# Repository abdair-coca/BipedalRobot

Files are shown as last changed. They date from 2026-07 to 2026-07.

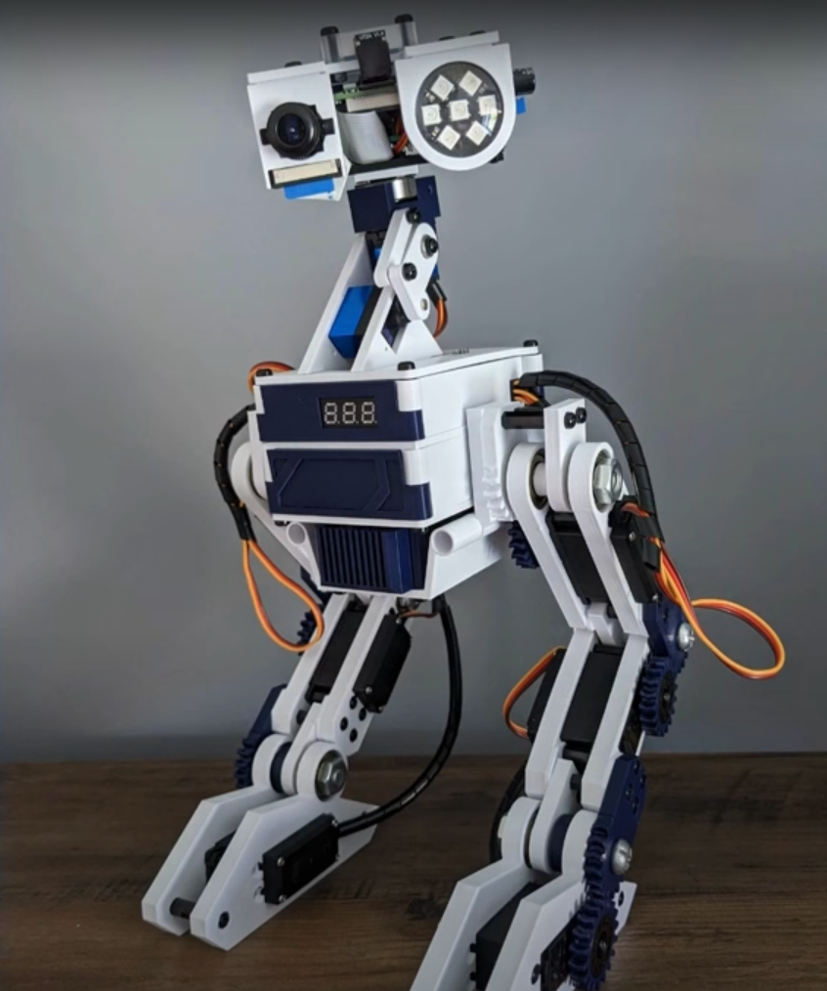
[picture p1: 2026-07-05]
docs/3dImages/propuesta.png

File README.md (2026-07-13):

# Bipedal Robot

Robot bipedo mediano (40-80cm) — proyecto portfolio/demo tecnico dentro del workspace **robotCreeper**.
Reutiliza y extiende el hardware/software ya desarrollado en robotCreeper (cabeza con camara, voz y cara OLED) montandolo sobre un cuerpo bipedo nuevo con piernas motorizadas y control de balance.

## Estructura del proyecto

| Carpeta | Contenido |
|---|---|
| [`docs/`](docs/) | Vision, alcance, arquitectura de sistema, roadmap, decisiones y riesgos |
| [`mecanica/`](mecanica/) | Diseno estructural, DOF de piernas, materiales |
| [`electronica/`](electronica/) | BOM, presupuesto energetico, conexionado |
| [`firmware/`](firmware/) | Arquitectura de firmware (ESP32 principal + nodos) |
| [`software/`](software/) | Control de marcha, cinematica, simulacion (a definir) |
| [`gestion/`](gestion/) | Backlog y milestones del proyecto |
| [`tests/`](tests/) | Tests de componentes especificos, aislados del firmware final |
| [`quadruped_rl_sim/`](quadruped_rl_sim/) | Experimento aislado: sim PyBullet+RL (PPO) de marcha en un cuadrupedo 12 DOF, previo a portar el enfoque al bipedo real |

## Punto de partida

- Empieza por [`docs/01-vision-alcance.md`](docs/01-vision-alcance.md)
- Arquitectura general en [`docs/02-arquitectura-sistema.md`](docs/02-arquitectura-sistema.md)
- Roadmap de fases en [`docs/03-roadmap-fases.md`](docs/03-roadmap-fases.md)

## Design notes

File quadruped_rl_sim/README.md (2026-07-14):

# quadruped_rl_sim

Simulacion PyBullet + Gymnasium + PPO (stable-baselines3) para entrenar la
marcha hacia adelante de un cuadrupedo generico de 12 DOF (3 por pata:
abduccion de cadera, pitch de cadera, rodilla).

**Este es un experimento aislado**, independiente del robot bipedo real del
resto del repo (`mecanica/`, `electronica/`, `firmware/`, etc.). Sirve como
banco de pruebas de RL con servos de posicion antes de portar el enfoque al
hardware bipedo. No comparte codigo ni archivos con esas carpetas.

## Por que cuadrupedo y no bipedo, para este experimento

Un cuadrupedo de 12 DOF es mas facil de estabilizar que un bipedo (mas puntos
de apoyo, menos sensible al balance), asi que sirve para validar primero la
mecanica de RL + control por posicion (URDF, entorno Gymnasium, PPO,
pipeline sim-to-real) con un problema mas simple, antes de pelear ademas con
el balance dificil de un bipedo.

## Instalacion

Requiere Python 3.11 (probado en Windows).

```bash
cd quadruped_rl_sim
python -m venv .venv
.venv\Scripts\activate         # cmd.exe
.venv\Scripts\Activate.ps1     # PowerShell
pip install -r requirements.txt
```

**Nota Windows importante**: `pybullet` no publica wheels precompilados para Windows
en PyPI (ninguna version) — `pip install` lo compila desde source, lo que requiere
**Microsoft C++ Build Tools** (workload "Desktop development with C++"). Si no los
tenes instalados, `pip install` va a fallar con `error: Microsoft Visual C++ 14.0 or
greater is required`. Instalar con:
```powershell
winget install --id Microsoft.VisualStudio.2022.BuildTools -e --override "--wait --quiet --add Microsoft.VisualStudio.Workload.VCTools --includeRecommended"
```
Alternativa sin compilar: instalar Miniconda y `conda install -c conda-forge pybullet`
(conda-forge si publica wheel `win-64`), el resto de las libs via pip igual.

## Archivos

| Archivo | Que hace |
|---|---|
| `config.py` | Todos los parametros fisicos del robot (dimensiones, masas, limites de joint en grados, altura de reposo). **Unico lugar a tocar cuando calibres el robot real.** |
| `generate_urdf.py` | Lee `config.py` y genera `quadruped.urdf` (torso + 4 patas x 3 joints revolute, colision con primitivas). Correr manualmente para regenerar, o se genera solo la primera vez que se instancia el entorno. |
| `quad_env.py` | `QuadrupedEnv(gymnasium.Env)`: observacion (31,), accion (12,) normalizada [-1,1] mapeada a angulos reales, reward, terminacion. Control por posicion (`POSITION_CONTROL`), no por torque. |
| `train.py` | Entrena PPO con `stable_baselines3`, entornos en paralelo (`SubprocVecEnv`), checkpoints periodicos, logging a `logs/` (tensorboard). |
| `enjoy.py` | Carga un `.zip` de SB3 y corre la politica en GUI, en tiempo real. |
| `view_model.py` | Abre el URDF actual en GUI, parado en la pose de reposo, sin entrenar ni cargar modelo -- para chequear proporciones/postura cuando quieras. |
| `requirements.txt` | Versiones pineadas, probadas juntas. |
| `colab_train.ipynb` | Entrena en Google Colab (gratis) en vez de tu laptop. Auto-resume, checkpoints persistidos en Drive, video del gait sin GUI. Ver seccion "Entrenar en la nube" abajo. |

## Uso

Generar el URDF (opcional, `quad_env.py` lo hace solo si falta):
```bash
python generate_urdf.py
```

Ver el diseno (proporciones, postura, colisiones) sin entrenar ni cargar ningun
modelo, cuando quieras:
```bash
python view_model.py
```

Entrenar:
```bash
python train.py --n-envs 8 --timesteps 2000000
```

Continuar un entrenamiento que se corto (Ctrl+C, cierre de terminal, corte de luz):
```bash
python train.py --resume checkpoints\ppo_quadruped_400000_steps.zip --timesteps 1600000
```
`--timesteps` acá es la cantidad ADICIONAL a correr desde donde quedo (no el total
absoluto), el contador de steps sigue sumando desde el checkpoint. Tensorboard va a
abrir una subcarpeta de log nueva para este tramo (mismo `--run-name` => se numera
sola, ej. `ppo_quadruped_2`) en vez de continuar literalmente la misma curva, pero el
eje de timesteps es continuo entre tramos.

Ver progreso en tensorboard:
```bash
tensorboard --logdir logs
```

## Entrenar en la nube (sin depender de la laptop)

Abrí `colab_train.ipynb` en [Google Colab](https://colab.research.google.com) (`Archivo >
Subir notebook`, o directo desde GitHub apuntando a este repo). Corre el mismo `train.py`
pero en los servidores de Colab: monta tu Google Drive, clona el repo ahí (así los
checkpoints sobreviven a que Colab te desconecte solo, cosa que hace cada rato), instala
`requirements.txt` (en Linux `pybullet` sí tiene wheel, no hace falta compilar como en
Windows), y entrena en tandas con auto-resume -- cada vez que volvés a correr la celda de
entrenamiento, sea el mismo día o diez días después, sigue desde el último checkpoint
guardado en Drive, no arranca de cero.

**Importante**: esto es CPU-bound (la física de PyBullet, no la red), la GPU gratis de
Colab no acelera nada acá -- dejá el runtime en CPU. Lo que sí importa es la cantidad de
vCPUs (gratis suele ser 2, similar o menos que una laptop, así que la ventaja no es
velocidad sino no tener que dejar la laptop prendida).

Como Colab no tiene pantalla, `enjoy.py` (que abre GUI) no sirve ahí -- el notebook
incluye una celda que graba la política en un `.mp4` en modo headless para verla inline
o bajarla de Drive.

Ver la politica entrenada:
```bash
python enjoy.py checkpoints/ppo_quadruped_final.zip
```

Smoke test rapido (pocos miles de steps, valida que todo el pipeline corre
sin errores de shape/tipo, no espera que camine bien):
```bash
python train.py --smoke-test --n-envs 2 --no-subproc
```

## Que esperar en el entrenamiento

Ordenes de magnitud, no numeros exactos (dependen de la semilla y de que
tan bien terminen quedando los parametros de `config.py`):

- **Primeros ~100k-300k timesteps**: la politica basicamente aprende a no
  caerse de inmediato. El reward promedio por episodio deberia subir desde
  muy negativo (cae casi enseguida, `REWARD_FALL_PENALTY` domina) hacia
  valores cercanos a 0 o levemente positivos.
- **~500k-1.5M timesteps**: empieza a aparecer movimiento hacia adelante
  consistente, aunque torpe/asimetrico. `ep_len_mean` (duracion de episodio)
  deberia acercarse a `MAX_EPISODE_STEPS` (1000) la mayor parte del tiempo.
- **2M+ timesteps**: marcha mas fluida y con mayor velocidad hacia adelante,
  si el reward shaping y los limites de joint son razonables. No hay
  garantia de una marcha "bonita" sin iterar sobre pesos de reward — el
  objetivo de esta base es que el pipeline funcione, no que el gait sea
  optimo en la primera corrida.

**Que mirar en tensorboard** (`tensorboard --logdir logs`):
- `rollout/ep_rew_mean`: debe tender a subir de forma sostenida (con ruido).
  Si se queda plano en un valor muy negativo por millones de steps, revisar
  pesos de reward o limites de joint (puede que el robot no tenga forma
  fisica de pararse con la pose de reposo configurada).
- `rollout/ep_len_mean`: debe subir hacia `MAX_EPISODE_STEPS`. Si se queda
  bajo (se cae siempre rapido), el problema esta antes de aprender a
  caminar: revisar altura/pose inicial en `config.py`.
- `train/explained_variance`: valores muy cercanos a 0 o negativos
  sostenidos indican que la funcion de valor no esta aprendiendo bien
  (puede necesitar mas `n_steps` o ajustar `learning_rate`).
- `train/approx_kl` y `train/clip_fraction`: si se disparan muy alto,
  la politica esta cambiando demasiado rapido entre updates (bajar
  `learning_rate` o `clip_range`).

## Proximos pasos

### Cuando tengas las medidas reales del robot

Editar **solo `config.py`**:
- `BODY_LENGTH` / `BODY_WIDTH` / `BODY_HEIGHT` / `BODY_MASS`: medidas y peso
  real del chasis (con bateria/electronica puesta, no solo la carcasa vacia).
- `FEMUR_LENGTH` / `TIBIA_LENGTH` / sus masas: largo real de los eslabones.
- `HIP_ABDUCTION_MIN/MAX_DEG`, `HIP_PITCH_MIN/MAX_DEG`, `KNEE_MIN/MAX_DEG`:
  rango mecanico real de cada servo/bracket (con margen de seguridad, no el
  limite fisico absoluto, para no forzar el servo).
- `JOINT_MAX_TORQUE` / `JOINT_MAX_VELOCITY`: de la hoja de datos del servo
  elegido, ya convertido a N*m y rad/s.
- `TARGET_STANDING_HEIGHT` y `STANDING_POSE_DEG`: pose de reposo real medida
  en el robot fisico (o la que quieras usar como punto de partida).

Despues de editar, correr `python generate_urdf.py` y volver a entrenar
desde cero (los limites de joint cambian el espacio de accion, un modelo
viejo no es directamente reusable si cambian mucho los limites).

### Transferencia sim-to-real

Con servos de posicion (no torque), el camino mas directo es:

1. **Extraer trayectorias, no correr la politica en vivo primero.** Cargar
   el modelo entrenado con `enjoy.py` (o un script similar sin GUI), correr
   varios episodios, y loguear la secuencia de 12 angulos objetivo por paso
   (`target_angles` en `quad_env.py`, ya en grados/radianes reales gracias
   al mapeo de `config.py`). Esto da una trayectoria "offline" que se puede
   inspeccionar, suavizar (filtro pasa-bajos entre steps consecutivos para
   no pedirle saltos bruscos al servo) y reproducir en el hardware real via
   PCA9685/servos sin que la laptop tenga que correr inferencia en el loop
   de control critico.
2. Validar esa trayectoria en el robot real con el torso sostenido/en un
   soporte (sin peso completo en las patas) para chequear que los angulos
   son alcanzables y no chocan mecanicamente antes de soltarlo al piso.
3. Recien despues, si hace falta reactividad (no solo replay de trayectoria
   fija), correr inferencia en vivo desde la laptop: leer sensores reales
   (por ahora ninguno mas que lo que ya tengas), construir la observacion
   (angulos/velocidades de los servos + IMU cuando este disponible) en el
   mismo formato que `quad_env.py`, llamar `model.predict()`, y mandar los
   angulos resultantes por el mismo canal de control que uses para los
   servos (igual patron que tu otro proyecto: control desde laptop, no
   on-board).
4. Cuando agregues el sensor de distancia, IMU y camara reales, extender
   `_get_obs()` en `quad_env.py` (y el `observation_space`) para que la
   politica los use durante el entrenamiento, no solo en inferencia —
   entrenar con la misma observacion que vas a tener disponible en runtime
   real evita el gap sim-to-real mas comun (politica que depende de datos
   que en el robot real no existen, ej. posicion absoluta global).

## Validado en esta sesion

- **pybullet en Windows**: no tiene wheel en PyPI (ninguna version) -- hubo que instalar
  Visual C++ Build Tools (`Microsoft.VisualStudio.2022.BuildTools`, workload C++) para que
  `pip install pybullet==3.2.7` compile desde source. Compila y funciona bien una vez
  instalados los Build Tools (~1-2 min de build). Ver nota en "Instalacion" arriba.
- **`requirements.txt`** actualizado a versiones actuales estables verificadas mutuamente
  compatibles contra el indice real de PyPI para Python 3.11 / win_amd64: numpy 2.3.5,
  torch 2.8.0, gymnasium 1.3.0, stable-baselines3 2.9.0, pybullet 3.2.7, tensorboard 2.20.0,
  tqdm 4.67.1, rich 14.2.0. Instalacion completa corrida de punta a punta sin errores.
- **URDF**: `generate_urdf.py` genero `quadruped.urdf` y cargo en PyBullet sin error.
  Confirmado: 16 joints (12 revolute + 4 fixed de pie), nombres y jerarquia correctos
  (`{pata}_hip_abduction_joint` -> `{pata}_hip_pitch_joint` -> `{pata}_knee_joint` -> `{pata}_foot_joint`).
- **`QuadrupedEnv`**: `reset()` + 500 `step()` con acciones aleatorias corridos sin crashear,
  observacion siempre shape `(31,)` y valores finitos, reward finito en cada step.
- **`train.py`** (smoke test, `--smoke-test`, ~4000 timesteps): corrido OK con `DummyVecEnv`
  (`--no-subproc`) y con `SubprocVecEnv` real (default, valida el guard `if __name__ ==
  "__main__":` necesario en Windows para multiprocessing) -- ambos terminaron sin errores de
  shape/tipo y guardaron el `.zip` final. Como es solo un smoke test (no entrenamiento real),
  los checkpoints/logs de esa corrida se borraron despues de validar (estan gitignored:
  `checkpoints/`, `logs/`, `quadruped.urdf` se regeneran solos).

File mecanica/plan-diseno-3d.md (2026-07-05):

# Plan de diseño 3D

Plan para modelar el bipedo completo en CAD 3D y validarlo (proporciones, rango de movimiento, colisiones, peso) **antes** de imprimir/cortar piezas reales. Complementa [diseno-estructural.md](diseno-estructural.md) (decisiones ya tomadas: DOF, materiales, ROM) con el flujo concreto de modelado.

## 1. Análisis de referencias (`docs/3dImages/`)

| Imagen | Qué es | Qué tomar de ella |
|---|---|---|
| `propuesta.png` | Bipedo impreso real, mismo enfoque de hardware que el nuestro (servos visibles tipo MG996R azules, cableado señal/potencia separado, cabeza con cámara+anillo LED, display frontal) | **Referencia principal de proporciones y solución de pie**: doble punto de apoyo (talón+punta) para ampliar área de sustentación sin sumar DOF. Bracket de cadera visible (2 servos casi coincidentes en el mismo punto pivote) — usar como referencia de ensamble cadera pitch+roll. |
| `bipedalrobot.png` | Render CAD de pierna con mecanismo de barras paralelas (four-bar linkage) y actuadores concentrados en la cadera, sin motor en rodilla/tobillo | **Solo inspiración mecánica avanzada, NO objetivo de v1.** Nuestra decisión ya tomada es servo directo en cada articulación vía PCA9685 (más simple y barato). No replicar el mecanismo de transmisión — dejarlo como posible upgrade de fase futura si el torque/inercia de v1 no alcanza (ver `docs/03-roadmap-fases.md` fase 3+). |
| `bipedalrobot1.jpg` | Render estético (carcasa curva, franjas de color) | **Solo referencia cosmética** para Fase 5 (pulido/carcasa). No afecta esqueleto, DOF ni ROM. |

**Importante**: no mezclar las tres referencias en un solo objetivo. El esqueleto cinemático sale de `propuesta.png` + `diseno-estructural.md`; el mecanismo de barras de `bipedalrobot.png` queda fuera de alcance de v1; la estética de `bipedalrobot1.jpg` es opcional y posterior.

## 2. Herramienta de CAD

Recomendado: **Fusion 360** (licencia personal/hobby gratuita) o **FreeCAD** (open source, sin cuenta). Ambas soportan:
- Modelado paramétrico (ajustar una medida sin rehacer la pieza)
- Ensamble con *joints*/*mates* que simulan el rango de movimiento real (clave para validar ROM sin imprimir)
- Detección de colisiones entre piezas en el ensamble
- Export a STEP (editable) y STL (impresión)

Tinkercad no alcanza para simular articulaciones — usar como mucho para bocetos rápidos, no para el ensamble final.

## 3. Especificación cinemática a modelar

8 DOF total (4 por pierna), heredado de `diseno-estructural.md`:

| Articulación | Eje | ROM | Servo |
|---|---|---|---|
| Cadera pitch | adelante/atrás | ±40° | MG996R |
| Cadera roll | lateral | ±20° | MG996R |
| Rodilla pitch | flexión | 0° a 90° | MG996R |
| Tobillo pitch | adelante/atrás | ±30° | MG996R |

Cadera pitch y cadera roll deben modelarse con pivotes lo más cercanos posible entre sí (bracket compartido, ver `propuesta.png`) para no alargar innecesariamente la pierna.

**Presupuesto de altura** (objetivo total 50-60cm):
1. Medir la cabeza existente físicamente (alto real, no asumido) — ya está construida, no se rediseña, solo se modela el bracket de unión cuello-torso.
2. Restar esa altura del objetivo total.
3. Repartir el resto entre torso (~12-15cm), muslo (~15-18cm), pantorrilla (~15-18cm) y pie (~5-8cm de largo), ajustando en el paso 2 del flujo (esqueleto en bloque) antes de detallar geometría.

## 4. Inventario de componentes a modelar

### Torso
- Chasis/caja principal (imprimir), con tapa desmontable para acceso a cableado.
- Aloja: ESP32 DevKit v1, PCA9685, MPU-6050, regulador buck 5V/3A, capacitor 1000-2200µF, batería (2S LiFePO4 o pack 4xAA NiMH).
- Reservar volumen para batería/PCA9685/capacitor en la parte **más baja** del torso (baja centro de masa, ya decidido en `diseno-estructural.md`).
- Puntos de anclaje para los 4 servos de cadera (2 por pierna).
- Canales separados para cable de señal (naranja) y potencia (negro) — ver `electronica/conexionado.md`.

### Cadera (x2, espejo izq/der)
- Bracket que combina servo roll + servo pitch cerca del mismo pivote.

### Muslo (x2, espejo)
- Eslabón rígido cadera→rodilla.
- Aloja 1x servo MG996R (rodilla) + horn + buje/rodamiento opcional en extremo superior.

### Pantorrilla (x2, espejo)
- Eslabón rígido rodilla→tobillo.
- Aloja 1x servo MG996R (tobillo).

### Pie (x2, espejo)
- Placa de apoyo con doble punto de contacto (talón+punta, referencia `propuesta.png`).
- Anclaje al horn del servo de tobillo.

### Cabeza
- No se remodela (ya existe físicamente). Solo modelar el bracket de unión al primer eslabón del torso.

## 5. Consideraciones de diseño

- **Tolerancias de impresión**: medir el horn del MG996R físico (no solo datasheet) y dejar 0.1-0.2mm de holgura en encastres.
- **Peso**: estimar peso por pieza en el slicer (volumen x densidad de infill) y sumarlo; comparar contra torque real de MG996R (riesgo ya documentado en `docs/04-riesgos-decisiones.md`).
- **Simetría**: modelar 1 pierna completa paramétrica y espejar para la otra — evita duplicar trabajo y asimetrías por error.
- **Validar ROM en CAD antes de imprimir**: simular los 4 extremos de movimiento (cadera pitch ±40°, cadera roll ±20°, rodilla 0-90°, tobillo ±30°) en el ensamble y confirmar que ninguna pieza choca con otra.

## 6. Flujo de modelado (orden sugerido)

1. Medir cabeza existente (alto, ancho, peso real).
2. Bloquear **esqueleto cinemático** en CAD: solo ejes/pivotes con formas primitivas (cilindros), respetando la tabla de DOF+ROM+presupuesto de altura — valida proporciones antes de detallar geometría.
3. Modelar 1 muslo + 1 pantorrilla + 1 pie con detalle real (encastres, horns, canales de cable).
4. Modelar bracket de cadera + unión a torso.
5. Modelar torso con volúmenes reservados por componente electrónico.
6. Ensamblar cadena completa (torso + 2 caderas + 2 muslos + 2 pantorrillas + 2 pies), simular ROM extremos, revisar colisiones.
7. Espejar la pierna validada para el lado restante.
8. Exportar STEP (backup editable) + STL (impresión), un archivo por pieza.
9. Imprimir **1 pierna de prueba primero** (no las 2 en paralelo) para validar ajuste real de servo/tornillería antes de comprometer todo el filamento.

## 7. Estructura de archivos propuesta

```
mecanica/cad/
  piezas/
    torso_chasis.step / .stl
    cadera_bracket_izq.step / .stl
    muslo_izq.step / .stl
    pantorrilla_izq.step / .stl
    pie_izq.step / .stl
    (piezas _der = espejo de _izq, no duplicar archivo fuente si la herramienta soporta mirror)
  ensamble/
    bipedalrobot_ensamble.step (o extensión nativa del software elegido)
```

Crear esta carpeta recién al empezar el modelado real (no antes, para no dejar carpetas vacías sin contenido).

## 8. Checklist antes de imprimir

- [ ] Esqueleto cinemático valida altura total dentro de 50-60cm
- [ ] Simulación de ROM sin colisiones en los 4 extremos por pierna
- [ ] Encastres de servo verificados contra medidas reales del MG996R físico
- [ ] Espacio interno del torso valida que entran todos los componentes con margen de cableado
- [ ] Peso estimado por pieza sumado y comparado contra torque disponible de servos

## 9. Checklist antes de pasar a fabricación real (Fase 1 del roadmap)

- [ ] Modelo 3D completo aprobado (visual + ROM + peso)
- [ ] 1 pierna impresa de prueba, servo montado, rango de movimiento a mano confirmado sin choques
- [ ] Ajuste de tornillería/horn probado en pieza real (no solo en CAD)
- [ ] Iterar CAD si hay diferencia entre simulación y pieza real, antes de imprimir el resto

## 10. Referencias cruzadas

- [diseno-estructural.md](diseno-estructural.md) — DOF, materiales, ROM, distribución de peso
- [docs/04-riesgos-decisiones.md](../docs/04-riesgos-decisiones.md) — riesgo de torque insuficiente
- [electronica/BOM.md](../electronica/BOM.md) — componentes a comprar/reusar
- [electronica/conexionado.md](../electronica/conexionado.md) — separación cables señal/potencia
- [docs/03-roadmap-fases.md](../docs/03-roadmap-fases.md) — Fase 1 (mecánica de piernas)

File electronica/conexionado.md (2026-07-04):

# Conexionado (pinout)

## Motion Controller — ESP32 DevKit v1 (nuevo)

### I2C bus (compartido: MPU-6050 + PCA9685)
| Señal | Pin ESP32 |
|---|---|
| SDA | GPIO 21 |
| SCL | GPIO 22 |
| MPU-6050 VCC | 3.3V |
| MPU-6050 GND | GND |
| MPU-6050 addr | 0x68 (default) |
| PCA9685 VCC (logica) | 5V (rail logica) |
| PCA9685 V+ (servos) | Rail servos (bateria, NO desde ESP32) |
| PCA9685 GND | GND comun con ESP32 y con rail servos |
| PCA9685 addr | 0x40 (default) |

### Canales PCA9685 -> servos (default 8 DOF, 4 por pierna)
| Canal | Articulacion |
|---|---|
| 0 | Cadera pitch (adelante/atras) - pierna izq |
| 1 | Cadera roll (lateral) - pierna izq |
| 2 | Rodilla pitch - pierna izq |
| 3 | Tobillo pitch - pierna izq |
| 4 | Cadera pitch (adelante/atras) - pierna der |
| 5 | Cadera roll (lateral) - pierna der |
| 6 | Rodilla pitch - pierna der |
| 7 | Tobillo pitch - pierna der |
| 8-11 | Libres — reservados para upgrade a 12 DOF (cadera yaw, tobillo roll) |

### UART/debug
| Señal | Pin ESP32 |
|---|---|
| USB serie (programacion/debug) | Puerto USB integrado |

## Head Node — Wemos D1 mini (ESP8266, existente, sin cambios)
| Componente | Pin D1 mini |
|---|---|
| OLED SH1106 SDA | D2 (GPIO4) |
| OLED SH1106 SCL | D1 (GPIO5) |
| MAX9814 salida analoga | A0 |
| PAM8403 entrada audio | Salida PWM/DAC (segun implementacion actual) |
| Servo pan | D5 (GPIO14) |
| Servo tilt | D6 (GPIO12) |

*(Mantener el pinout que ya tiene robotCreeper funcionando — esta tabla es referencia, no forzar cambio si el proyecto original usa otros pines.)*

## Vision Node — ESP32-CAM (existente, sin cambios)
- Sin modificaciones, sigue con su configuracion actual de camara + WiFi.

## Comunicacion entre nodos

**Protocolo recomendado**: ESP-NOW (WiFi peer-to-peer sin router, baja latencia, ideal para comandos cortos tipo "estado=caminando").

Alternativa mas simple de implementar si ya existe infraestructura WiFi local: UDP/MQTT sobre la misma red WiFi de casa.

| Mensaje | Direccion | Contenido |
|---|---|---|
| Estado de movimiento | Motion Controller -> Head Node | `idle` / `walking` / `fallen` |
| Comando de expresion | Head Node -> Motion Controller (opcional, fase futura) | ej. reaccion a algo que ve la camara |

## Tierra comun (GND)

Todos los nodos y ambos rails de alimentacion (servos y logica) deben compartir GND comun, aunque tengan fuentes de voltaje separadas. Sin GND comun el I2C y las señales digitales no funcionan.

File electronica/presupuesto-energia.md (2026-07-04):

# Presupuesto energetico

## Rails de alimentacion (separados, no compartir tierra ruidosa entre ambos sin capacitor/regulador)

### Rail 1 — Servos de piernas (alta corriente, ruidoso)
- 8x MG996R: stall current ~1.5-2A c/u en pico, tipico en movimiento ~0.5-0.9A c/u.
- Peor caso teorico (los 8 en stall simultaneo): ~12-16A — **no diseñar para este caso**, es improbable con buen firmware (evitar comandar todos los servos contra un tope a la vez).
- Diseño realista: 3-4 servos en movimiento simultaneo tipico durante un paso -> ~3-6A pico.
- **Fuente recomendada**: bateria 2S LiFePO4 6.4V con capacidad continua >5A, o pack 4xAA NiMH (4.8V) para version mas economica si el torque alcanza.
- Capacitor de 1000-2200uF en los terminales de alimentacion del PCA9685/servos para absorber picos rapidos.

### Rail 2 — Logica (ESP32, ESP8266, MPU-6050, PCA9685 logica I2C)
- ESP32 DevKit: ~160-260mA activo (WiFi transmitiendo, pico).
- ESP8266 (Wemos D1 mini): ~80-170mA activo con WiFi.
- MPU-6050: ~4mA.
- OLED SH1106: ~10-20mA.
- MAX9814 + PAM8403: ~10-100mA dependiendo de volumen.
- **Total rail logica**: <600mA en el peor caso realista.
- **Fuente recomendada**: regulador buck 5V/3A alimentado desde la misma bateria principal (o bateria separada chica), NO desde el rail de servos directo (evita brownouts que resetean el ESP32 al mover servos).

## Por que separar rails

Servos moviendose generan caidas de tension bruscas en la fuente. Si ESP32/ESP8266 comparten esa misma fuente sin regulacion propia, un movimiento brusco de servo puede resetear el microcontrolador (sintoma tipico: el robot "reinicia solo" al caminar). Separar rails (con tierra comun, pero regulacion independiente) es la solucion estandar en robotica con servos.

## Autonomia estimada

- Bateria 2S LiFePO4 ~1500-2000mAh: con consumo promedio de marcha (~2-3A promedio, no pico) da aprox. **30-45 min de uso activo** — mas que suficiente para demos/pruebas.
- Pack 4xAA NiMH ~2000mAh: similar orden de magnitud pero menor corriente maxima sostenida, valido si los servos no exigen picos altos simultaneos.

## Checklist antes de energizar todo junto

1. Medir voltaje real de bateria antes de conectar (evitar sobretension a servos/logica).
2. Probar rail logica solo (sin servos) primero.
3. Probar 1 servo solo en rail de servos, verificar que no cae tension en rail logica.
4. Recien despues conectar los 8-12 servos juntos al PCA9685.

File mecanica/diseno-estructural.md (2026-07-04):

# Diseño estructural

## Dimension objetivo
40-80cm de alto total (torso + piernas + cabeza existente). Recomendado apuntar a **~50-60cm** para primera version: suficientemente grande para alojar componentes, suficientemente chico para minimizar torque necesario en servos economicos (menos alto = menos palanca = menos torque requerido).

## DOF por pierna — comparacion

### Opcion A (default recomendado): 4 DOF/pierna = 8 total
- Cadera pitch (adelante/atras)
- Cadera roll (lateral, clave para balance lateral)
- Rodilla pitch
- Tobillo pitch
**Ventaja**: mas barato (8 servos), mas simple de controlar y debuggear. Suficiente para marcha estatica basica.
**Limitacion**: sin cadera-yaw no gira facil sobre su eje; sin tobillo-roll el balance lateral fino depende solo de cadera-roll.

### Opcion B (upgrade futuro): 6 DOF/pierna = 12 total
Agrega cadera yaw + tobillo roll. Mejor marcha, giros mas naturales, mejor balance — pero mas caro, mas peso, mas complejo de calibrar. Dejar para fase posterior si Opcion A resulta limitada (ver docs/03-roadmap-fases.md fase 3).

## Materiales (de mas economico a mas robusto)

1. **Carton pluma / MDF liviano cortado**: mas barato, mas rapido de iterar, suficiente para prototipo funcional. Riesgo: menor durabilidad, flexion en piezas largas.
2. **PLA impreso 3D (infill 15-20%)**: buen balance costo/rigidez, permite piezas con encastres para servos (cuernos de servo, bisagras). Recomendado si hay acceso a impresora 3D.
3. **Aluminio/acrilico cortado laser**: mas robusto y durable, mas caro y requiere mas herramental. Considerar solo si el proyecto escala mas alla de portfolio inicial.

**Default recomendado**: PLA impreso 3D si hay impresora disponible (mejor para encastre de servos), carton pluma/MDF como alternativa cero-inversion si no.

## Distribucion de peso

- Bateria(s) y componentes pesados (PCA9685, cableado) ubicar lo mas bajo posible (cerca de cadera/pies) para bajar centro de masa -> mejora estabilidad y reduce torque necesario en tobillos.
- Cabeza (ESP32-CAM + OLED + mic + amp + 2 servos pan/tilt) es la carga mas alta del robot — mantenerla lo mas liviana posible, ya que su peso multiplica el torque exigido en cadera/tobillo por efecto palanca.

## Rango de movimiento minimo por articulacion (referencia inicial, ajustar en pruebas)

| Articulacion | Rango |
|---|---|
| Cadera pitch | ±40° |
| Cadera roll | ±20° |
| Rodilla pitch | 0° a 90° (no hiperextender) |
| Tobillo pitch | ±30° |

## Validacion mecanica antes de firmware de marcha

1. Mover cada servo manualmente (sin carga) y confirmar rango sin choques mecanicos entre piezas.
2. Parar el robot sostenido a mano, confirmar que geometria de piernas permite centro de masa dentro del area de apoyo de los pies.
3. Pesar el robot completo armado — validar contra torque real de servos (ver docs/04-riesgos-decisiones.md, riesgo de torque insuficiente).

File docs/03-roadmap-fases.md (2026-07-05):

# Roadmap por fases

## Fase 0 — Prep y validacion de electronica (1-2 semanas)
- Validar ESP32 DevKit + PCA9685 + 1-2 servos de prueba (loop basico de PWM).
- Validar lectura de MPU-6050 (angulos pitch/roll estables, sin drift grave).
- Confirmar que subsistema de cabeza (Wemos D1 mini + OLED + mic + amp) sigue funcionando standalone.
- Salida: banco de pruebas electronico funcionando en mesa (sin estructura fisica aun).

## Fase 1 — Mecanica de piernas (2-4 semanas)
- Definir DOF final por pierna (ver [mecanica/diseno-estructural.md](../mecanica/diseno-estructural.md)).
- Diseñar y validar el modelo 3D completo antes de imprimir (ver [mecanica/plan-diseno-3d.md](../mecanica/plan-diseno-3d.md)).
- Modelar/imprimir o cortar piezas de piernas + torso.
- Montar 12 servos + estructura, sin electronica final aun (solo prueba mecanica de rango de movimiento a mano).
- Salida: estructura bipeda armada, se puede mover manualmente cada articulacion.

## Fase 2 — Balance estatico (2-3 semanas)
- Firmware: loop de lectura IMU + PID simple sobre tobillos/cadera.
- Robot se sostiene parado sin caerse, corrige perturbaciones chicas (empujones leves).
- Salida: robot parado solo >30s sin asistencia.

## Fase 3 — Marcha estatica (3-5 semanas)
- Generar secuencia de pasos precalculada (cinematica inversa simple, ver [software/control-marcha.md](../software/control-marcha.md)).
- Ajustar timing y balance de peso entre piernas durante el paso.
- Salida: robot camina 3-5 pasos en linea recta sin caerse.

## Fase 4 — Integracion con cabeza/robotCreeper (1-2 semanas)
- Conectar Motion Controller <-> Wemos D1 mini <-> ESP32-CAM via WiFi.
- Sincronizar expresiones de cara con estado de movimiento (parado/caminando/caido).
- Salida: robot completo, cuerpo + cabeza funcionando juntos.

## Fase 5 — Pulido y demo (1-2 semanas)
- Cableado prolijo, fijacion de baterias, carcasa/cosmetica basica.
- Grabar video demo, actualizar documentacion con fotos/resultados reales.
- Salida: demo presentable para portfolio.

## Notas
- Tiempos son estimados trabajando part-time (hobby/portfolio), ajustar segun disponibilidad real.
- Cada fase tiene su propio criterio de "salida" — no se avanza de fase sin cumplirlo, evita acumular deuda tecnica que despues es dificil debuggear (mecanica + balance mal hecho es muy dificil de diagnosticar en capas superiores).

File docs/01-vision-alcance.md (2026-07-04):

# Vision y alcance

## Que es

Robot bipedo mediano (40-80cm de alto) que camina, balancea y hereda las capacidades de interaccion (vision, voz, cara) del proyecto robotCreeper existente. Es el "cuerpo" nuevo para la "mente/cabeza" ya construida.

## Objetivo

Portfolio/demo tecnico: debe quedar bien documentado, con hitos demostrables (parado estatico -> balance dinamico -> caminata) y presentable (video, fotos, repo ordenado).

## Alcance cubierto por esta organizacion

- **Mecanico**: estructura de piernas/torso, DOF, materiales, impresion 3D o corte.
- **Electronico**: BOM completo, presupuesto energetico, conexionado.
- **Firmware/software**: control de balance (IMU), cinematica de piernas, gestion de marcha, integracion con nodos de robotCreeper.
- **Gestion**: backlog, fases, milestones, riesgos.

## Fuera de alcance (por ahora)

- Manipulacion (brazos) — puede ser fase futura, no bloquea el proyecto actual.
- Marcha dinamica avanzada (ZMP completo, control por RL) — se empieza con marcha estatica/cuasi-estatica.

## Relacion con robotCreeper

robotCreeper ya tiene resuelto: vision (ESP32-CAM), voz (mic MAX9814 + amp PAM8403), cara (OLED SH1106), movimiento de cabeza (2 servos pan/tilt), y una base rodante (TT motors + L298N + Wemos D1 mini/ESP8266).

Este proyecto bipedo:
- **Reutiliza** el subsistema de cabeza (camara, voz, cara, pan/tilt) tal cual, montado en la parte superior del nuevo cuerpo.
- **Reemplaza** la base rodante (TT motors + L298N) por piernas motorizadas con servos — la base rodante NO sirve para bipedo, ver [decisiones](04-riesgos-decisiones.md).
- **Agrega** un controlador principal nuevo (ESP32 DevKit) dedicado a balance y locomocion, usando el MPU-6050 ya disponible.
- Detalle de integracion en [02-arquitectura-sistema.md](02-arquitectura-sistema.md).

## Criterio de exito (portfolio)

1. Robot se para solo y mantiene balance estatico.
2. Robot camina unos pasos en linea recta (marcha estatica).
3. Cabeza (vision+voz+cara) sigue funcionando integrada en el cuerpo nuevo.
4. Documentacion + video demo presentables.

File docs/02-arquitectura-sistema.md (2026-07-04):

# Arquitectura de sistema

## Vision general (nodos)

```
                     ┌───────────────────────────┐
                     │     ESP32 DevKit v1        │
                     │   "Motion Controller"      │
                     │  (NUEVO - cerebro locomocion)│
                     ├───────────────────────────┤
                     │ - Lee MPU-6050 (I2C)       │
                     │ - Loop de balance          │
                     │ - Genera trayectorias      │
                     │ - Controla PCA9685 (I2C)   │
                     │   -> 12x servo piernas      │
                     └───────────┬───────────────┘
                                 │ WiFi (ESP-NOW o MQTT local)
                 ┌───────────────┼───────────────────┐
                 │                                   │
     ┌───────────▼───────────┐           ┌───────────▼───────────┐
     │ Wemos D1 mini (ESP8266)│           │   ESP32-CAM            │
     │  "Head Node" (existente)│           │  "Vision Node" (existente)│
     ├────────────────────────┤           ├────────────────────────┤
     │ - OLED SH1106 (cara)   │           │ - Streaming/captura     │
     │ - MAX9814 mic          │           │ - Reconocimiento (fase 2)│
     │ - PAM8403 + speaker    │           └────────────────────────┘
     │ - 2x servo pan/tilt    │
     │   (cuello/cabeza)      │
     └────────────────────────┘
```

## Por que 3 microcontroladores y no 1

- Ya existen 2 (Wemos D1 mini, ESP32-CAM) corriendo el subsistema de cabeza de robotCreeper — no se reescribe lo que ya funciona.
- El loop de balance (leer IMU + corregir servos) necesita correr rapido y sin bloqueos de red/camara -> se aisla en su propio ESP32 dedicado.
- Comunicacion entre nodos es de bajo trafico (comandos: "mirar arriba", "decir frase", "expresion feliz") -> WiFi local alcanza, no hace falta bus fisico entre cabeza y cuerpo (mas facil de ensamblar mecanicamente).

## Main loop del Motion Controller (ESP32 nuevo)

1. Leer IMU (angulo pitch/roll del torso).
2. Calcular correccion (PID simple sobre tobillos/cadera).
3. Actualizar posiciones objetivo de los 12 servos via PCA9685.
4. Si hay comando de marcha activo, avanzar siguiente frame de la secuencia de pasos precalculada.
5. Publicar estado (parado/caminando/caido) a Wemos D1 mini para que la cara reaccione (ej: cara de esfuerzo al caminar, cara de "auch" si se cae).

## Alimentacion (resumen, detalle en electronica/presupuesto-energia.md)

- Rail servos (piernas): bateria dedicada 6-7.4V, alta corriente.
- Rail logica (ESP32, ESP8266, sensores): 5V/3.3V regulado, separado del rail de servos.
- Cabeza (pan/tilt + OLED + audio): puede compartir rail de logica, son cargas chicas.

## Que pasa con el hardware que NO se usa en el bipedo

- **L298N + 4x TT motors**: no aplican a piernas (son para ruedas). Se guardan para otro proyecto (rover) o como base de pruebas temporal del ESP32 nuevo antes de tener piernas armadas. Ver [04-riesgos-decisiones.md](04-riesgos-decisiones.md).

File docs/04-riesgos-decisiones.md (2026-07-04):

# Decisiones tecnicas y riesgos

## Decisiones clave

### 1. TT motors + L298N no se usan para piernas
**Por que**: TT motors son de rotacion continua (ruedas), no dan control de posicion angular preciso que necesita una articulacion de pierna. Torque tambien insuficiente y mal distribuido para soportar peso corporal en una pierna.
**Que hacer con ellos**: quedan reservados para un futuro rover/base rodante, o como carrito de pruebas temporal para validar el ESP32 nuevo antes de tener piernas armadas (fase 0).

### 2. Servos elegidos para piernas: MG996R (o equivalente metal gear economico)
**Por que**: economicos (~$3-5 c/u), torque suficiente (~9-11 kg·cm @6V) para un bipedo de 40-80cm liviano (impreso 3D), disponibilidad alta, ampliamente documentados en proyectos DIY similares.
**Alternativa descartada**: SG90 (plastico, ~1.8kg·cm) — insuficiente para articulaciones que cargan peso (cadera, rodilla, tobillo). Sirve solo para pan/tilt de cabeza (uso actual, no cambia).
**Alternativa mas cara**: Dynamixel — mejor control (feedback de posicion, bus serie), pero 10-20x mas caro por unidad. Descartado por presupuesto ajustado, se puede migrar despues si el proyecto escala.

### 3. Cantidad de DOF por pierna: 4 (opcion economica) vs 6 (opcion completa)
Ver detalle y tradeoff en [mecanica/diseno-estructural.md](../mecanica/diseno-estructural.md). Default recomendado: **4 DOF/pierna (8 total)** para fase 1, dejar cadera-yaw y tobillo-roll como upgrade fase futura si el balance con 4 DOF resulta insuficiente.

### 4. Un ESP32 nuevo dedicado a locomocion, en vez de reusar Wemos D1 mini existente
**Por que**: el D1 mini (ESP8266) ya esta ocupado con cabeza (OLED+mic+amp+2 servos) y tiene menos pines/menor performance que ESP32. El loop de balance necesita I2C rapido (IMU) + I2C a PCA9685 sin competir con audio/display.

### 5. PCA9685 como driver de servos (nuevo, a comprar)
**Por que**: ESP32 no tiene 12 salidas PWM de hardware libres y estables simultaneamente de forma comoda: PCA9685 da 16 canales PWM dedicados via I2C, barato (~$2), estandar en proyectos de robotica con muchos servos.

## Riesgos

| Riesgo | Impacto | Mitigacion |
|---|---|---|
| Servos MG996R insuficientes en torque real (spec inflada, comun en clones baratos) | Alto — no se sostiene parado | Comprar 1-2 de mas para testear antes de pedir el lote completo; dejar margen de rediseño mecanico (reducir peso/palanca) |
| Cada de tension al mover varios servos a la vez (brownout del ESP32) | Alto — reinicios random | Rail de servos separado de rail logica (ver electronica/presupuesto-energia.md), capacitor grande en rail servos |
| Peso de estructura impresa en 3D mayor al estimado | Medio — mas torque necesario | Iterar diseno con infill bajo, materiales livianos, pesar cada pieza impresa |
| MPU-6050 con drift/ruido (clones baratos son comunes) | Medio — balance inestable | Filtro complementario o Kalman simple en firmware, calibracion en frio al encender |
| Scope creep: agregar brazos/manipulacion antes de caminar bien | Alto — proyecto nunca termina | Fuera de alcance explicito (ver vision-alcance.md), revisar backlog antes de agregar features |
| Tiempo de desarrollo subestimado (hobby, tiempo parcial) | Medio | Fases con criterio de salida claro, se puede pausar entre fases sin perder progreso |

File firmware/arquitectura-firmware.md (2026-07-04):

# Arquitectura de firmware

## Motion Controller (ESP32 DevKit, nuevo) — Arduino framework (C++)

### Librerias
- `Adafruit_PWMServoDriver` — control PCA9685.
- `MPU6050` (ej. Electronic Cats o I2Cdevlib) o lectura cruda + filtro propio — para IMU.
- `WiFi.h` + `esp_now.h` — comunicacion con Head Node.

### Estructura de modulos
```
firmware/motion-controller/
├── motion-controller.ino     # setup() + loop()
├── imu.h/.cpp                # lectura MPU-6050, filtro complementario, angulos pitch/roll
├── servo_driver.h/.cpp        # wrapper sobre PCA9685, mapeo angulo->pulso por canal
├── balance.h/.cpp             # PID de balance, correccion sobre cadera/tobillo
├── gait.h/.cpp                # secuencias de marcha precalculadas (lookup de poses por frame)
├── comms.h/.cpp                # ESP-NOW: enviar estado, recibir comandos
└── config.h                   # pines, direcciones I2C, limites de angulo por servo
```

### Loop principal (pseudo-codigo)
```cpp
void loop() {
  imu.update();                      // lee angulos actuales
  float correction = balance.pid(imu.pitch, imu.roll);

  if (gait.isWalking()) {
    gait.advanceFrame();             // siguiente pose de la secuencia de marcha
  }

  servo_driver.applyPose(gait.currentPose(), correction);
  comms.publishState(gait.state());  // idle/walking/fallen
  comms.checkIncoming();             // comandos externos si los hay

  delay(LOOP_INTERVAL_MS);           // ej. 20ms -> 50Hz
}
```

### Deteccion de caida (simple, fase 2)
- Si `abs(pitch) > UMBRAL` o `abs(roll) > UMBRAL` sostenido por N ciclos -> estado `fallen`, cortar marcha, opcionalmente relajar servos para no forzar motor contra el piso.

## Head Node (Wemos D1 mini, existente) — sin reescritura
- Se mantiene el firmware actual de robotCreeper.
- **Unico agregado**: listener ESP-NOW que recibe el estado (`idle`/`walking`/`fallen`) y dispara la expresion/animacion de cara correspondiente en el OLED.

## Vision Node (ESP32-CAM, existente) — sin cambios
- No requiere cambios para el alcance de este proyecto (fase 4 en adelante podria integrarse mas, ver docs/03-roadmap-fases.md).

## Calibracion

- **MPU-6050**: calibrar offset en frio al arrancar (robot parado quieto sobre superficie plana), guardar offsets en `config.h` o EEPROM.
- **Servos**: cada servo fisico tiene su propio offset de "centro" mecanico — mapear en `config.h` un array de trim por canal (`SERVO_TRIM[8]`) para no depender de que todos los servos esten fisicamente centrados igual.

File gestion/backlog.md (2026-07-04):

# Backlog

Organizado por fase (ver [docs/03-roadmap-fases.md](../docs/03-roadmap-fases.md)). Marcar con `[x]` al completar.

## Fase 0 — Prep y validacion de electronica
- [ ] Armar banco de pruebas: ESP32 + PCA9685 + 1 servo MG996R
- [ ] Escribir firmware minimo: mover 1 servo entre 2 angulos via PCA9685
- [ ] Conectar MPU-6050, leer y loguear angulos crudos por serial
- [ ] Implementar filtro complementario basico sobre IMU
- [ ] Confirmar Wemos D1 mini + OLED + mic + amp siguen funcionando standalone (regresion)
- [ ] Comprar 2 servos MG996R sueltos y testear torque real con carga aproximada

## Fase 1 — Mecanica de piernas
- [ ] Definir DOF final (default: 4/pierna, ver mecanica/diseno-estructural.md)
- [ ] Modelar piezas (CAD) o cortar carton pluma/MDF segun material elegido
- [ ] Imprimir/cortar piezas de pierna izquierda (prototipo)
- [ ] Validar rango de movimiento sin choques mecanicos
- [ ] Replicar para pierna derecha
- [ ] Montar torso, fijar piernas, dejar espacio para bateria y PCA9685
- [ ] Pesar robot completo armado (sin electronica final)

## Fase 2 — Balance estatico
- [ ] Implementar PID de balance (cadera-roll + tobillo-pitch) sobre lectura IMU
- [ ] Calibrar offsets de servo (trim por canal)
- [ ] Calibrar offset IMU en frio
- [ ] Probar parado libre, medir tiempo sin caerse
- [ ] Probar resistencia a perturbacion leve (empujon)
- [ ] Implementar deteccion de caida (estado `fallen`)

## Fase 3 — Marcha estatica
- [ ] Definir poses clave del ciclo de paso (ver software/control-marcha.md)
- [ ] Implementar interpolacion entre poses (`gait.cpp`)
- [ ] Ajustar timing empiricamente
- [ ] Ajustar amplitud de transferencia de peso
- [ ] Integrar correccion PID en tiempo real sobre la secuencia de marcha
- [ ] Lograr 3-5 pasos consecutivos sin caerse

## Fase 4 — Integracion con cabeza
- [ ] Implementar ESP-NOW entre Motion Controller y Head Node
- [ ] Head Node reacciona a estado (`idle`/`walking`/`fallen`) con expresion en OLED
- [ ] Validar que cabeza no interfiere con balance (peso, cableado)

## Fase 5 — Pulido y demo
- [ ] Cableado prolijo, fijar bateria(s)
- [ ] Cosmetica basica (carcasa simple si aplica)
- [ ] Grabar video demo
- [ ] Actualizar READMEs con fotos/resultados reales
- [ ] Revisar y cerrar riesgos abiertos (docs/04-riesgos-decisiones.md)

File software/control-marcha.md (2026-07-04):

# Control de marcha

## Enfoque general: marcha estatica por poses precalculadas (sin cinematica inversa compleja)

Para 4 DOF/pierna (cadera pitch, cadera roll, rodilla pitch, tobillo pitch) no hace falta resolver cinematica inversa general — alcanza con definir a mano una secuencia de **poses clave** (keyframes) y interpolar entre ellas. Es el enfoque estandar en bipedos hobby economicos.

## Definicion de pose

Una pose = angulo objetivo para cada uno de los 8 servos, en un instante del ciclo de paso.

```
Pose = {
  hip_pitch_L, hip_roll_L, knee_L, ankle_L,
  hip_pitch_R, hip_roll_R, knee_R, ankle_R
}
```

## Ciclo de paso basico (secuencia de poses, simetrica izq/der)

1. **Pose neutral**: parado, peso distribuido 50/50, piernas rectas.
2. **Transferir peso** a pierna de apoyo (ej. derecha): inclinar cadera-roll hacia el lado de apoyo.
3. **Levantar pierna libre** (izquierda): flexionar rodilla + cadera pitch hacia adelante, tobillo compensa para despegar el pie del piso.
4. **Avanzar pierna libre**: cadera pitch sigue moviendose adelante mientras la pierna esta en el aire.
5. **Apoyar pierna libre**: extender rodilla, bajar pie, tobillo ajusta para apoyo plano.
6. **Transferir peso** a la pierna que acaba de apoyar (ahora izquierda es de apoyo).
7. Repetir simetrico con la otra pierna.

Cada paso de la secuencia se interpola linealmente (o con suavizado tipo ease-in-out) entre pose anterior y siguiente, en N frames, para movimiento suave y no brusco (brusco = mas riesgo de caida y mas estres en servos economicos).

## Ajuste fino (se hace empiricamente en fase 3, no se puede calcular perfecto de antemano)

- **Timing**: cuanto dura cada fase del paso (ms) — empezar lento (500-800ms por fase) e ir acelerando conforme se valida estabilidad.
- **Amplitud de transferencia de peso**: cuanto se inclina la cadera-roll antes de levantar la pierna — insuficiente = se cae al levantar el pie; excesivo = se desestabiliza hacia el lado de apoyo.
- **Compensacion con IMU en tiempo real**: la secuencia de poses da la "forma" del paso, pero el PID de balance (firmware/arquitectura-firmware.md) corrige sobre esa forma en tiempo real segun el angulo real medido — no seguir la secuencia ciegamente si el IMU detecta desbalance.

## Herramienta de calibracion sugerida (opcional, acelera fase 2-3)

Script simple (Python o web serial) que permite mover cada servo individualmente desde una PC via serial, para:
- Encontrar visualmente los angulos clave de cada pose sin tener que editar y re-flashear firmware cada vez.
- Guardar la secuencia final como constantes en `gait.cpp`.

## Fuera de alcance (fase futura, no bloquea portfolio)

- ZMP (Zero Moment Point) dinamico completo.
- Aprendizaje por refuerzo para la marcha.
- Marcha adaptativa a terreno irregular.

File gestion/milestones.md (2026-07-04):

# Milestones

Cada milestone corresponde a la salida de una fase (ver [docs/03-roadmap-fases.md](../docs/03-roadmap-fases.md)). Criterio binario: cumple o no cumple, sin ambiguedad.

## M0 — Banco de pruebas electronico
**Criterio**: 1 servo se mueve via PCA9685 comandado por ESP32; MPU-6050 entrega angulos estables por serial; subsistema de cabeza (existente) sigue funcionando sin regresiones.
**Estado**: pendiente

## M1 — Estructura mecanica armada
**Criterio**: piernas + torso ensamblados, las 8 articulaciones se mueven manualmente en su rango completo sin choques ni obstrucciones.
**Estado**: pendiente

## M2 — Balance estatico
**Criterio**: robot parado libre (sin sostener) mantiene equilibrio >30 segundos, se recupera de un empujon leve sin caerse.
**Estado**: pendiente

## M3 — Marcha estatica
**Criterio**: robot ejecuta 3-5 pasos consecutivos en linea recta sin caerse, arrancando y terminando parado estable.
**Estado**: pendiente

## M4 — Cuerpo + cabeza integrados
**Criterio**: robot completo (piernas + torso + cabeza) funciona como una unidad; la cara reacciona visualmente al estado de movimiento (parado/caminando/caido).
**Estado**: pendiente

## M5 — Demo final presentable
**Criterio**: video demo grabado mostrando M2-M4 en secuencia, documentacion actualizada con resultados reales (fotos, specs finales, lecciones aprendidas).
**Estado**: pendiente

## Tracking

| Milestone | Fecha objetivo | Fecha real | Notas |
|---|---|---|---|
| M0 | - | - | - |
| M1 | - | - | - |
| M2 | - | - | - |
| M3 | - | - | - |
| M4 | - | - | - |
| M5 | - | - | - |

*(Completar fechas objetivo segun disponibilidad real de tiempo — ver docs/03-roadmap-fases.md para estimados de duracion por fase.)*

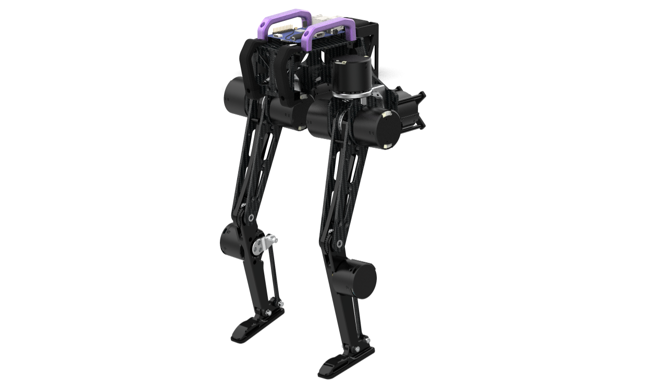
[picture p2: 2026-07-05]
docs/3dImages/bipedalrobot.png

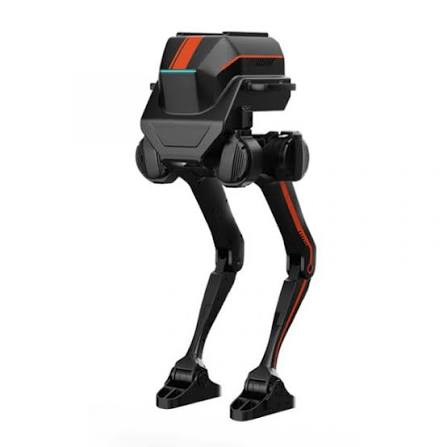
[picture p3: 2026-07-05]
docs/3dImages/bipedalrobot1.jpg

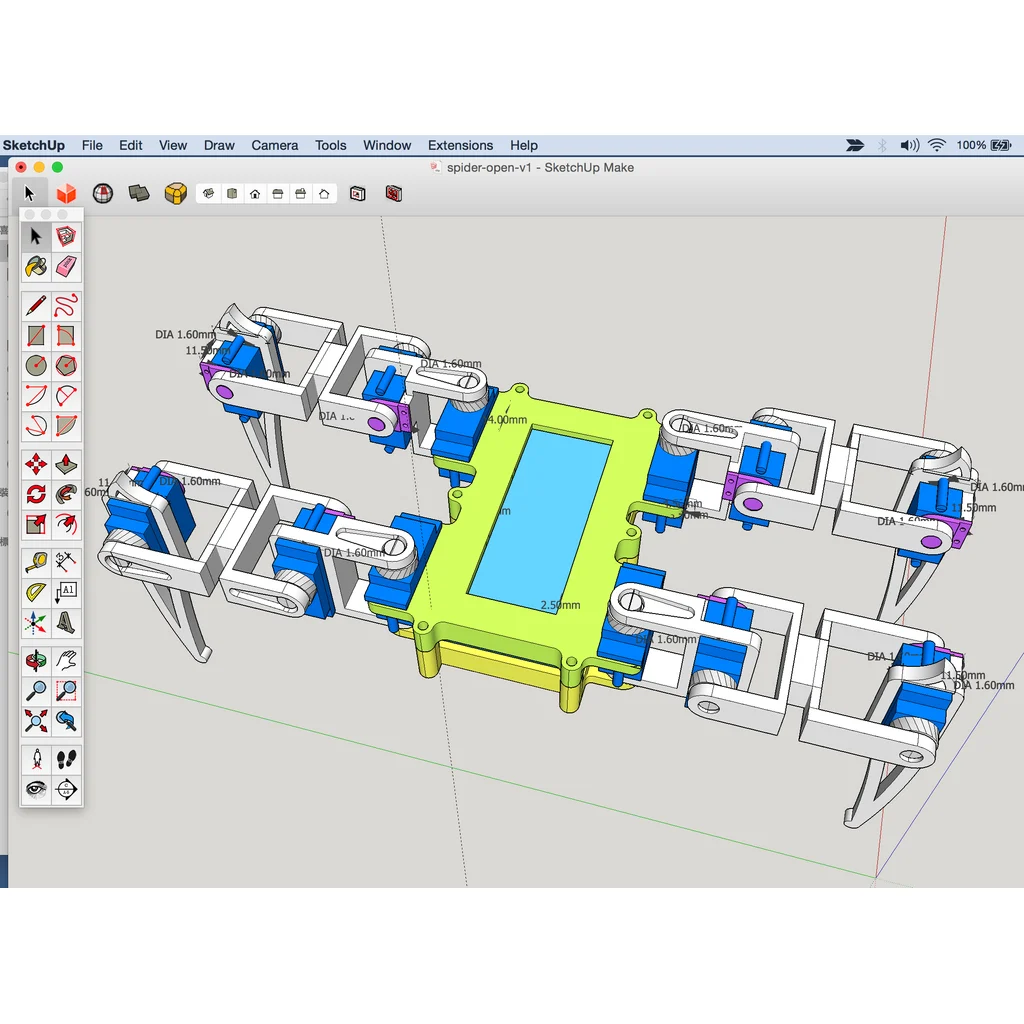
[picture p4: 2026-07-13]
docs/3dImages/spiderRobotQuadruped.png

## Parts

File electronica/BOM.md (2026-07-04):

# BOM (Bill of Materials)

Precios estimados en USD, referencia AliExpress/proveedor economico. Ajustar segun mercado local.

## Ya disponible (heredado de robotCreeper)

| Componente | Rol en el bipedo | Cantidad | Estado |
|---|---|---|---|
| ESP32 DevKit v1 | Puede usarse como Motion Controller nuevo | 1 | Integrado (reasignar rol) |
| ESP32-CAM | Vision Node, sin cambios | 1 | Integrado |
| SH1106 OLED 1.3" I2C | Cara del robot, sin cambios | 1 | Integrado |
| MAX9814 microfono | Entrada de voz, sin cambios | 1 | Integrado |
| PAM8403 amplificador | Salida de audio, sin cambios | 1 | Integrado |
| Servos pan/tilt (x2) | Cuello/cabeza, sin cambios | 2 | Integrado |
| Wemos D1 mini (ESP8266) | Head Node (OLED+mic+amp+pan/tilt) | 1 | Integrado |
| MPU-6050 | IMU para balance del torso — **uso nuevo** | 1 | Integrado |
| L298N driver | No aplica a piernas, reservar para otro proyecto | 1 | No usado en este proyecto |
| Motores TT (x4) | No aplica a piernas, reservar para otro proyecto | 4 | No usado en este proyecto |
| Baterias 2-5V | Reusar si alcanzan corriente, si no ver abajo | ? | Evaluar en campo |

## A comprar (piernas + locomocion)

| Componente | Rol | Cantidad | Precio est. c/u | Subtotal |
|---|---|---|---|---|
| Servo MG996R (metal gear) | Articulaciones de piernas (cadera, rodilla, tobillo) | 8-12 | ~$3.50 | $28-42 |
| PCA9685 (driver PWM 16ch I2C) | Control de todos los servos de pierna desde 1 solo bus I2C | 1 | ~$2.00 | $2.00 |
| ESP32 DevKit v1 (segundo, si el existente se deja libre para otra cosa) | Motion Controller dedicado | 0-1 | ~$4.00 | $0-4 |
| Bateria 2S LiFePO4 6.4V (o pack 4xAA NiMH 4.8-5V como alternativa mas barata) | Rail de servos (alta corriente) | 1 | ~$8-12 | $8-12 |
| Regulador buck 5V/3A (para rail logica separado) | Alimentar ESP32/ESP8266/sensores sin ruido de servos | 1 | ~$1.50 | $1.50 |
| Capacitor electrolitico grande (1000-2200uF, 16V) | Amortiguar picos de corriente en rail servos | 1-2 | ~$0.50 | $0.50-1 |
| Rodamientos/bujes chicos (opcional, mejora durabilidad de articulaciones) | Cadera/rodilla | 4-8 | ~$0.30 | $1.20-2.40 |
| Filamento PLA (estructura impresa) o carton pluma/MDF liviano (alternativa mas barata aun) | Estructura piernas + torso | ~0.5-1kg | ~$15-20/kg | $8-20 |
| Tornilleria M2/M3 variada | Ensamblaje | 1 kit | ~$3 | $3 |

**Subtotal a comprar (estimado, 8 DOF / 12 DOF)**: ~$52-88 (8 DOF) a ~$66-102 (12 DOF), dependiendo de cantidad de servos y eleccion de bateria/estructura.

## Notas de economia

- Empezar con **8 servos (4 DOF/pierna)** reduce costo ~$14-21 vs 12, y es el default recomendado (ver [docs/04-riesgos-decisiones.md](../docs/04-riesgos-decisiones.md)).
- Estructura en carton pluma/MDF o PLA con infill bajo (15-20%) es mas barata y mas liviana que aluminio — prioridad para bipedo economico.
- Pack 4xAA NiMH recargable es la opcion mas barata para rail de servos si el torque/corriente alcanza en pruebas; LiFePO4 es mejor opcion si se necesita mas corriente sostenida.
- Comprar 1-2 servos sueltos primero para testear torque real antes de pedir el lote completo (ver riesgo en docs/04-riesgos-decisiones.md).

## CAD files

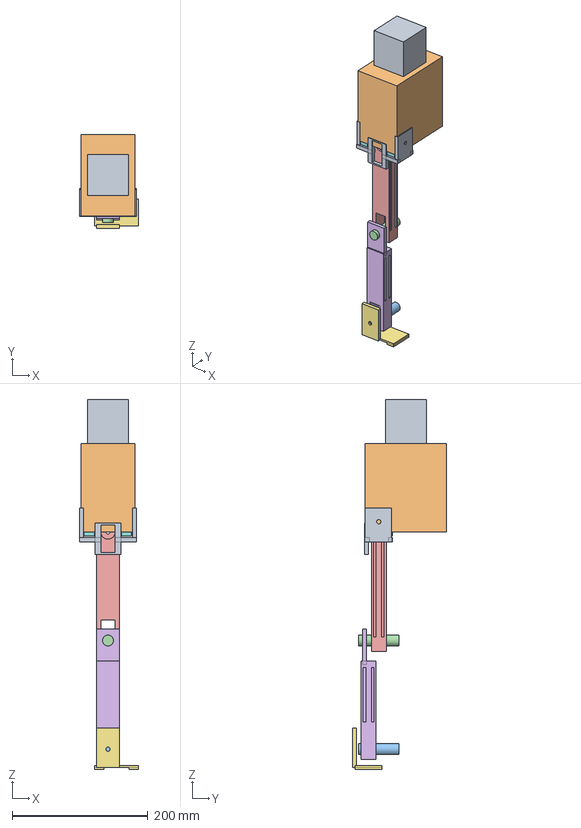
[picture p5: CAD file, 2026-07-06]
mecanica/cad/ensamble/bipedalrobot_ensamble.FCStd
87.0 x 139.0 x 545.0 mm
Stub_Reserva_Cabeza
Torso
Eje_Tobillo_Pitch_Izq
Eje_Rodilla_Pitch_Izq
Muslo_Izq
Pantorrilla_Izq
Pie_Izq
Bracket_Cadera_Roll_Izq
Bracket_Cadera_Pitch_Izq

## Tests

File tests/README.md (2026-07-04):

# Tests de componentes

Seccion para probar hardware/codigo de forma aislada, **antes** de integrar al firmware final del bipedo. Cada test valida un componente o subsistema especifico (sensor, driver, control) con el hardware que ya esta disponible, sin depender de que la mecanica final este lista.

## Por que esta seccion existe

El bipedo tiene piezas que tardan (mecanica, servos nuevos). Mientras tanto se puede validar codigo/electronica critica reusando hardware ya disponible (ej: L298N + TT motors, que no van en las piernas pero sirven de plataforma de pruebas). Esto reduce riesgo: cuando llegue el momento de integrar todo, el codigo de sensores/control ya esta probado por separado.

## Convencion de cada test

Cada test vive en su propia carpeta `test-NN-nombre-descriptivo/` con:
- `README.md` — objetivo, hardware requerido, wiring, como correrlo, criterio de exito/fallo, troubleshooting.
- Codigo fuente (`.ino` u otro) — listo para flashear, con comentarios donde el "por que" no es obvio (constantes de calibracion, tuning, seguridad).

## Indice de tests

| # | Test | Componente probado | Estado |
|---|---|---|---|
| 01 | [mpu6050-balance-ruedas](test-01-mpu6050-balance-ruedas/) | MPU-6050 + PID de balance, usando L298N + TT motors como plataforma provisoria (controlador: ESP8266/Wemos D1 mini, Arduino) | Sensor+sentido validados, en tuning |
| 02 | [calibracion-pid](test-02-calibracion-pid/) | Mismo hardware que 01, firmware con comandos por Serial para tunear KP/KI/KD/SETPOINT_ANGLE en vivo sin reflashear, con guardado en EEPROM | Listo para usar |

## Relacion con el firmware final

La logica de lectura de IMU + filtro complementario + PID probada aca es la misma que despues se traslada a `firmware/motion-controller/imu.*` y `balance.*` (ver [firmware/arquitectura-firmware.md](../firmware/arquitectura-firmware.md)), solo que actuando sobre motores de rueda en vez de servos de pierna. Validar el loop de balance en ruedas primero es mas rapido/barato que esperar a tener las piernas armadas para descubrir si el PID o la lectura de IMU tienen problemas.

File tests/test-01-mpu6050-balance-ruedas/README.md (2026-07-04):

# Test 01 — MPU-6050 + balance sobre ruedas (TT motors)

## Objetivo

Validar, de forma aislada y sin depender de la mecanica del bipedo (que aun no esta lista), el loop completo de:
1. Lectura de IMU (MPU-6050).
2. Filtro de angulo (complementario).
3. Control PID de balance.
4. Actuacion sobre motores (L298N + TT motors).

Se arma un robot de 2 ruedas tipo pendulo invertido (self-balancing robot) usando hardware que **ya esta disponible** y que **no se va a usar en las piernas del bipedo** (ver `docs/04-riesgos-decisiones.md`, decision #1). Es la forma mas rapida y barata de probar que el sensor y el algoritmo de balance funcionan antes de gastar tiempo/plata en piernas si el approach de control tiene problemas.

## Controlador de este test: ESP8266 (Wemos D1 mini), no el ESP32

Estado actual del hardware: el **ESP32 DevKit tiene MicroPython** cargado, y el **Wemos D1 mini (ESP8266) tiene Arduino (C++)**. Este test se implementa en el **ESP8266 con Arduino**, para no depender de reflashear el ESP32.

**Nota**: si esta misma placa D1 mini es la que normalmente corre el firmware de Head Node del proyecto principal (OLED + mic + amp + servos pan/tilt), este test es un flash **temporal** — hay que reflashear el firmware original del Head Node al terminar. Los pines usados aca no coinciden con los del Head Node (ver `electronica/conexionado.md`) porque no corren al mismo tiempo.

## Por que este test primero

Es el test de mayor riesgo tecnico del proyecto entero: si el MPU-6050 (clon barato) tiene demasiado ruido/drift, o si el PID no logra estabilizar nada, mejor descubrirlo ahora, en una plataforma simple de 2 ruedas, que despues de meses de imprimir/armar piernas.

La logica de sensado/control probada aca (IMU + filtro + PID) es conceptualmente la misma que se documenta en `firmware/arquitectura-firmware.md` para el Motion Controller final — cambia el actuador (motores DC en vez de servos) y el microcontrolador (ESP8266 en este test vs. ESP32 en el diseño final).

## Hardware requerido

| Componente | Origen | Notas |
|---|---|---|
| Wemos D1 mini (ESP8266) | Ya disponible (BOM) | Controlador de este test |
| MPU-6050 | Ya disponible (BOM) | Montado rigido, eje alineado con la inclinacion del chasis |
| L298N driver | Ya disponible (BOM) | Reservado para pruebas, no va en piernas |
| TT motors x4 | Ya disponible (BOM) | 2 en paralelo por lado (izq/der) para mas torque, o 1 por lado si alcanza |
| Ruedas x2 (o x4 si van pareadas) | A conseguir si no hay | Diametro grande ayuda a la estabilidad (mas facil de balancear) |
| Chasis simple (carton/MDF/impreso) | A armar | Alto y angosto favorece el efecto pendulo invertido, mas facil de controlar que uno bajo y ancho |
| Bateria motores (6-12V segun specs TT motors) | Ver `electronica/presupuesto-energia.md` | Rail separado de logica, mismo criterio que el proyecto principal |
| Bateria/regulador logica ~5V (D1 mini acepta 5V por su regulador a bordo, o 3.3V directo) | Ver `electronica/presupuesto-energia.md` | Alimenta el D1 mini y el MPU-6050 |

## Nota sobre los "strapping pins" (D0/D3/D4/D8)

En teoria D0(GPIO16), D3(GPIO0), D4(GPIO2) y D8(GPIO15) son sensibles al boot del ESP8266 (si algo externo los fuerza a cierto nivel durante el arranque, la placa puede no bootear bien). En la practica, en esta placa especifica, D0/D3/D4 conectados directo al L298N (como entradas del L298N, que son de alta impedancia) **funcionan sin problema** — confirmado en banco de pruebas. Por eso el wiring final usa los 2 canales del L298N **independientes** (sin atarlos entre si), dejando el robot listo para un futuro test de giro/direccion sin tener que recablear nada. D8 queda libre.

Si en otra placa/otro L298N esto llegara a causar boot loops, la alternativa segura es atar ENA-ENB y IN1-IN3/IN2-IN4 entre si y controlar todo con 3 pines (D1/D2 I2C + D5 PWM + D6/D7 direccion), sacrificando la capacidad de girar.

## Wiring

### MPU-6050 (I2C)
| MPU-6050 | Wemos D1 mini |
|---|---|
| VCC | 3.3V |
| GND | GND |
| SDA | D2 (GPIO4) |
| SCL | D1 (GPIO5) |
| INT | No usado en este test |

### L298N (canales A y B independientes)
| L298N | Wemos D1 mini | Rol |
|---|---|---|
| ENA | D3 (GPIO0) | PWM canal A (rueda izquierda) |
| IN1 | D0 (GPIO16) | Direccion canal A |
| IN2 | D5 (GPIO14) | Direccion canal A |
| ENB | D4 (GPIO2) | PWM canal B (rueda derecha) |
| IN3 | D6 (GPIO12) | Direccion canal B |
| IN4 | D7 (GPIO13) | Direccion canal B |
| GND | GND comun con el D1 mini y la bateria de motores | |
| +12V (o voltaje de los TT motors) | Bateria motores (rail separado) | |
| 5V salida logica L298N | **No usar** para alimentar el D1 mini directo — usar rail regulado propio (ver `electronica/presupuesto-energia.md`) | |
| OUT1 + OUT2 | 2x TT motors lado izquierdo, en paralelo | |
| OUT3 + OUT4 | 2x TT motors lado derecho, en paralelo | |

D8 (GPIO15) queda libre en este wiring.

**GND comun obligatorio** entre bateria motores, bateria/regulador logica y el D1 mini, o el I2C y las lecturas van a fallar / comportarse erratico.

## Montaje fisico

- MPU-6050 fijo rigido al chasis (sin holgura), con el eje que mide "inclinacion adelante/atras" alineado con la direccion de rodado.
- Centro de masa del chasis lo mas alto posible respecto al eje de las ruedas ayuda a que el sistema sea mas facil de balancear al principio (mas inercia, cae mas lento) — se puede afinar despues.
- Dejar acceso facil al puerto USB del D1 mini para iterar rapido en la calibracion del PID.

## Como correr el test

1. En Arduino IDE, seleccionar board **"LOLIN(WEMOS) D1 R2 & mini"** (o "WeMos D1 R1", segun version exacta de la placa).
2. Flashear `balance_ruedas.ino`.
3. Con el robot **apoyado sobre un soporte** (sin tocar el piso con las ruedas, ej. sostenido en el aire o sobre un caballete), abrir el Monitor Serial a 115200 baudios.
4. Confirmar que se leen angulos de pitch estables y que cambian correctamente al inclinar el chasis a mano (probar ambos sentidos).
5. Dejar el robot quieto y plano unos segundos al arrancar — el codigo calibra el offset del giroscopo en frio (ver seccion "Calibracion" abajo).
6. Recien con la lectura de angulo validada, apoyar el robot en el piso, sostenido a mano, y soltar de a poco viendo si los motores reaccionan en la direccion correcta (si se inclina adelante, las ruedas deben girar hacia adelante para "perseguir" la caida, no al reves — si reaccionan al reves, invertir el signo de la correccion o el cableado de IN1/IN2 e IN3/IN4).
7. Ajustar constantes `KP`, `KI`, `KD` del PID (al inicio del archivo) de forma iterativa (ver "Tuning" abajo).

## Calibracion

- **Offset de giroscopo**: el codigo promedia N lecturas al arrancar con el robot quieto y plano, y resta ese offset en cada lectura subsiguiente. Si el robot no arranca plano y quieto, el offset queda mal y el angulo va a driftear.
- **Angulo neutral (`SETPOINT_ANGLE`)**: el angulo de pitch en el que el robot esta perfectamente balanceado depende de donde quedo montado el MPU-6050 fisicamente (raramente es exactamente 0°). Ajustar esta constante hasta que el robot "quiera quedarse quieto" en su punto de equilibrio real.

## Tuning del PID (orden recomendado)

1. Empezar con `KI = 0` y `KD = 0`, subir `KP` de a poco hasta que el robot reaccione a la inclinacion (aunque oscile fuerte) — confirma que la direccion de correccion es correcta.
2. Agregar `KD` de a poco para amortiguar la oscilacion (reduce el "temblor" rapido).
3. Agregar `KI` de a poco solo si el robot se estabiliza pero queda inclinado hacia un lado de forma sostenida (compensa el offset residual).
4. Si en cualquier punto el robot se descontrola cada vez mas rapido (en vez de estabilizarse), el signo de la correccion esta invertido — revisar cableado de IN1/IN2 e IN3/IN4 o el signo en el codigo, no seguir subiendo ganancias.

## Criterio de exito

- El robot se mantiene parado sobre sus 2 ruedas sin caerse por >15-20 segundos en piso plano.
- Se recupera de un empujon leve (unos cm de desplazamiento del pendulo) sin caerse.
- Las lecturas de IMU no muestran drift visible en el Monitor Serial durante ~1 minuto quieto.

No hace falta que camine ni se desplace — este test es solo de **balance estatico en el lugar**, igual que el Milestone M2 del proyecto principal pero en ruedas en vez de piernas.

## Troubleshooting

| Sintoma | Causa probable |
|---|---|
| D1 mini se reinicia solo al mover motores | Falta rail de energia separado (logica vs motores) o falta capacitor, ver `electronica/presupuesto-energia.md` |
| Angulo lee valores absurdos o saltos bruscos | GND no comun entre bateria motores y logica, o cableado I2C flojo |
| Angulo driftea lento con el robot quieto | Calibracion de offset de giroscopo mala (robot no estaba quieto/plano al arrancar) o filtro complementario con `ALPHA` mal ajustado |
| Robot se cae siempre para el mismo lado | `SETPOINT_ANGLE` mal calibrado, o motor de un lado mas debil/lento que el otro (revisar mecanicamente, no solo en software) |
| Robot oscila cada vez mas fuerte hasta caerse | Signo de correccion invertido, o `KP`/`KD` demasiado altos — bajar ganancias y volver a subir de a poco |
| No compila / `analogWriteRange` no reconocido | Confirmar que el board seleccionado en Arduino IDE es un ESP8266 (no AVR/ESP32) — esa funcion es especifica del core ESP8266 |
| Motor zumba fuerte / chillido audible | Normal en PWM de baja frecuencia (~1kHz default de `analogWrite` en ESP8266); se puede subir con `analogWriteFreq()` si molesta, con cuidado de no perder resolucion de PWM |
| D1 mini no bootea o queda en loop de reset al conectar el L298N | En esta placa D0/D3/D4 se confirmaron sin problema; si en la tuya da bootloop, pasar a la alternativa segura (atar ENA-ENB e IN1-IN3/IN2-IN4), ver seccion "Nota sobre los strapping pins" |

## Registro de resultados

Completar despues de correr el test (agregar filas segun iteraciones de tuning):

| Fecha | KP | KI | KD | Resultado | Notas |
|---|---|---|---|---|---|
| - | - | - | - | - | - |

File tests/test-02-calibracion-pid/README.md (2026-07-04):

# Test 02 — Calibracion en vivo del PID de balance

## Objetivo

Ajustar `KP`, `KI`, `KD` y `SETPOINT_ANGLE` del balance sobre ruedas **sin reflashear** cada vez que se cambia un valor. Es la continuacion natural de [Test 01](../test-01-mpu6050-balance-ruedas/) una vez que el sentido de correccion ya esta confirmado — acá se hace el ajuste fino real.

Mismo hardware y mismo wiring que Test 01 (ver esa carpeta para wiring completo). Este test es **solo firmware distinto**: sirve una pagina web de control (sin cable) y ademas acepta los mismos comandos por Serial, mas persistencia en EEPROM para no perder los valores encontrados al reiniciar.

## Panel web (sin cable, recomendado para probar en el piso)

El cable USB tira del robot justo cuando mas molesta (mientras intenta corregir el balance). El D1 mini crea su propia red WiFi y sirve una pagina de control — no depende de un cable ni de la red de casa:

1. Conectate a la red WiFi `BalanceBot` (contraseña `equilibrio`, definidas al principio del `.ino`, cambialas si queres) desde el celular o la PC.
2. Abrí `http://192.168.4.1` en el navegador.
3. La pagina muestra en vivo el angulo, la salida al motor y el estado (armado/desarmado/caido), con campos para KP/KI/KD/Setpoint/Zona muerta/Filtro derivada y botones ARMAR / PARAR / Recalibrar / Guardar en EEPROM.
4. Cambiar un campo y tocar **APLICAR** manda todos los valores juntos. **PARAR** es el boton grande rojo — parada de emergencia, no corta la placa ni pierde valores.

El Monitor Serial sigue funcionando en paralelo con los mismos comandos de texto (`p6.5`, `e`, `x`, etc. — ver tabla abajo), util para debug con cable durante el desarrollo o para ver el arranque/IP antes de que el celular se conecte.

## Por que separado de Test 01

Test 01 sirve para confirmar que sensor+filtro+sentido de correccion funcionan (ya lo validaron). A partir de ahi, encontrar los valores finales de PID es un proceso iterativo de prueba y error — reflashear por cada cambio de un numero es lento y ademas cada reset reinicia el robot fisicamente (hay que levantarlo, sostenerlo, etc). Este test elimina esa friccion.

## Protocolo de comandos (Monitor Serial, 115200 baudios, terminar cada linea con Enter)

| Comando | Efecto |
|---|---|
| `p<valor>` | Setea KP. Ej: `p6.5` |
| `i<valor>` | Setea KI. Ej: `i0.1` |
| `d<valor>` | Setea KD. Ej: `d0.3` |
| `s<valor>` | Setea SETPOINT_ANGLE. Ej: `s-1.2` |
| `e` | **Arma** los motores (empiezan a corregir con los gains actuales) |
| `x` | **Desarma** los motores — parada de emergencia, no corta la placa ni pierde los valores |
| `c` | Recalibra el offset del giroscopo (robot quieto y plano en ese momento) |
| `z<valor>` | Setea la zona muerta del motor (PWM minimo para que la rueda gire). Ej: `z60` |
| `f<valor>` | Setea el suavizado de la derivada, 0-0.99 (mas alto = mas suave/lento). Ej: `f0.7` |
| `w` | Guarda KP/KI/KD/SETPOINT_ANGLE/DEADZONE actuales en EEPROM (sobreviven a reinicios/reflasheos) |
| `g` | Imprime estado actual: gains, deadzone, angulo, armado/desarmado |
| `h` o `?` | Imprime esta ayuda |

El robot **arranca siempre desarmado** (motores quietos) al bootear, aunque haya valores guardados en EEPROM — hay que mandar `e` a proposito cada vez para que empiece a corregir. Esto es intencional: evita que el robot salga andando solo apenas se le da alimentacion.

## Como correr el test

1. Flashear `calibracion_pid.ino` (una sola vez — de ahi en mas no hace falta volver a subir nada para tunear). Necesita las librerias `ESP8266WiFi` y `ESP8266WebServer` (vienen incluidas con el core ESP8266 de Arduino, no hay que instalar nada aparte).
2. Abrir Monitor Serial a 115200 baudios (con cable, para ver el arranque) — ahi aparece la IP para el panel web.
3. Al bootear, el sketch calibra el giroscopo (robot quieto y plano) e imprime el estado inicial.
4. Conectate a la red `BalanceBot` desde el celular/PC y abrí `http://192.168.4.1` — de ahi en mas ya podes desconectar el cable USB.
5. Con el robot **sostenido en un soporte** (no en el piso todavia), tocar **ARMAR** y probar el sentido de correccion (ya validado en Test 01, pero confirmar de nuevo si cambiaron algo del hardware).
6. Ir ajustando los campos y tocando **APLICAR**, observando angulo/output que se actualiza en vivo.
7. Recien cuando el robot se sostenga bien sostenido/soltado con cuidado en la mano, probar en el piso — ahora sin cable de por medio.
8. Cuando encuentres valores que funcionan, tocar **Guardar en EEPROM**.

## Ejemplo de sesion de tuning

```
> g
KP=6.00 KI=0.00 KD=0.00 SETPOINT=0.00 pitch=0.42 motores=desarmados

> e
Motores ARMADOS

(se prueba, tiembla mucho con KP=6, se baja)
> p4.0
KP=4.00

(se prueba, reacciona pero lento, se sube un poco)
> p5.0
KP=5.00

(se agrega amortiguacion)
> d0.2
KD=0.20

(se calibra el punto de equilibrio real sosteniendolo derecho a mano y mirando el angulo que marca ahi)
> s-1.35
SETPOINT_ANGLE=-1.35

(se prueba en el piso, se banca solo unos segundos pero se va inclinando de a poco para un lado)
> i0.08
KI=0.08

(anda bien, se guarda)
> w
Guardado en EEPROM.
```

## Notas de seguridad

- El robot arranca **desarmado**: siempre `e` antes de esperar reaccion.
- `x` corta motores al instante sin resetear la placa ni perder los valores probados — usarlo como boton de panico si algo se descontrola.
- Deteccion de caida (>35° de inclinacion respecto al setpoint) sigue activa igual que en Test 01, corta motores automaticamente sin importar el estado de armado.
- Si el robot arranca con valores guardados en EEPROM que resultan ser malos (oscila fuerte apenas armas), mandar `x` inmediatamente y volver a ajustar antes de rearmar.

## Zona muerta del motor (MOTOR_DEADZONE)

Los TT motors (gearbox + friccion estatica) no giran con cualquier PWM chico — por debajo de cierto valor el motor recibe señal pero no se mueve. Si el PID pide una correccion menor a ese umbral, el robot cae libre sin que el motor reaccione, hasta que el error crece lo suficiente — ahi el motor arranca de golpe con overshoot. Esto produce oscilaciones grandes en vez de correcciones finas.

El firmware compensa esto: cualquier salida de PID distinta de cero se "levanta" como minimo a `MOTOR_DEADZONE` antes de mandarla al motor.

### Como calibrar MOTOR_DEADZONE

1. Con el robot desarmado (`x`) y las ruedas en el aire (sin tocar el piso), mandar `p0 i0 d0` para anular el PID.
2. Inclinar el chasis un poco para generar un error chico y armar (`e`) — o mas simple, subir manualmente el valor con pruebas de `p` bajito.
3. Alternativa directa: usar el codigo de Test 01 o un sketch chico aparte para probar `analogWrite` directo en un canal con valores crecientes (30, 40, 50, 60...) y ver a partir de cual valor la rueda arranca a girar de forma visible. Ese valor (con un margen, +10) es tu `MOTOR_DEADZONE`.
4. Setealo con `z<valor>` (default en el codigo: 60) y ajustar por prueba y error si las ruedas siguen sin reaccionar a errores chicos, o si arrancan demasiado bruscas.

## Si el robot sobrecorrige (rebota de un lado al otro sin asentarse)

Sintoma: las ruedas reaccionan muy fuerte/rapido, se pasa de largo, corrige para el otro lado con la misma fuerza, nunca se estabiliza. Esto es sobrecorreccion clasica (KP efectivo demasiado alto para el sistema), no limite fisico — si viste proyectos con el mismo hardware que si balancean, confirma que es de tuning.

**Reiniciar el tuning desde abajo, no seguir desde 25-35:**

1. `x` para desarmar. `p2 i0 d0` — volver a empezar bajo, ganancias que ya probaste (20-35) muy probablemente ya estan en zona de divergencia (los valores crudos de output que viste, cientos por encima de 255, confirman que el error se estaba amplificando demasiado).
2. Recalibrar `MOTOR_DEADZONE` al minimo real: probar con `p0 i0 d0` y subir `z` de a poco (`z20`, `z30`, `z40`...) hasta que la rueda arranque a girar de forma visible con el robot inclinado apenas. Un deadzone mas alto de lo necesario ya empuja una correccion mas fuerte de lo que el error amerita — es probable que z60 este sobrecorrigiendo errores chicos.
3. Con deadzone real seteado, subir `p` de a 1 en 1 (no de a 5 o 10) sosteniendo el robot cerca de su equilibrio, buscando el punto donde reacciona proporcional a la inclinacion (poco angulo = correccion suave, harto angulo = correccion fuerte) sin ya estar a maxima velocidad para inclinaciones chicas.
4. Ahi sumar `d` de a poco (`d0.1`, `d0.3`...) para amortiguar el resto del rebote.
5. Si el rebote sigue siendo erratico/nervioso (no un rebote lento y amplio, sino algo tembloroso), bajar `f` (mas cerca de 0.9, por defecto 0.7) para suavizar mas la derivada, o subirlo si la correccion se siente con mucho retraso.

## Checklist mecanico si el PID solo no alcanza

Si con deadzone compensada + KP/KD razonables el robot sigue sin sostenerse, el problema es fisico, no de software. Probar en este orden (de mayor a menor impacto esperado con motores TT lentos):

1. **Subir el centro de masa** (chasis mas alto, peso concentrado arriba): esto hace que el robot caiga mas lento (aumenta el periodo natural del pendulo invertido), dando mas tiempo a un motor lento para reaccionar. Es el cambio de mayor impacto para motores TT.
2. **Aligerar el chasis**: menos masa total = menos torque necesario para corregir.
3. **Ruedas mas grandes**: mas desplazamiento lineal por vuelta de motor, ayuda a que la correccion "alcance" mas rapido en términos de distancia recorrida.
4. **Mejor agarre de rueda** (goma en vez de plastico liso): evita patinar, que desperdicia el torque justo cuando mas se necesita.
5. **Revisar la bateria de motores bajo carga**: medir el voltaje real mientras los motores estan exigidos (no en reposo) — si cae mucho, el motor pierde torque justo en el momento critico. Bateria debil se siente identico a "motor debil" aunque el motor este bien.
6. Si despues de todo esto sigue sin sostenerse: es limite fisico real de los TT motors para esta dinamica especifica (gearbox+RPM insuficiente) — el objetivo de validar sensor+filtro+PID ya esta cumplido igual, ver `docs/04-riesgos-decisiones.md`.

## Relacion con el resto del proyecto

Una vez encontrados los valores finales de `KP`/`KI`/`KD`/`SETPOINT_ANGLE` en este test, esos mismos valores (ajustados por la diferencia de actuador) son el punto de partida para el PID de balance del Motion Controller final del bipedo (ver `firmware/arquitectura-firmware.md` y `software/control-marcha.md`) — la ganancia exacta va a variar porque el actuador cambia de ruedas a servos, pero el orden de magnitud y el proceso de tuning es el mismo.

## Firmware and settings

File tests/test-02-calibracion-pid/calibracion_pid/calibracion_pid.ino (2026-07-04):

/*
 * Test 02 - Calibracion en vivo del PID de balance (web, sin cable)
 *
 * Ver README.md de esta carpeta para instrucciones de conexion, ejemplos de
 * sesion de tuning y notas de seguridad.
 *
 * Mismo hardware que Test 01 (tests/test-01-mpu6050-balance-ruedas/):
 * Wemos D1 mini + MPU-6050 + L298N + TT motors, mismo wiring.
 *
 * El D1 mini crea su propia red WiFi (ver WIFI_SSID/WIFI_PASSWORD abajo) y
 * sirve una pagina web de control en http://192.168.4.1 -- conectate a esa
 * red desde el celular o la PC y abrila en el navegador. El Monitor Serial
 * (USB, 115200 baudios) sigue funcionando en paralelo con los mismos
 * comandos de texto, util para debug con cable durante el desarrollo:
 *   p<valor>  i<valor>  d<valor>  s<valor>  z<valor>  f<valor>
 *   e (armar)  x (parar)  c (recalibrar)  w (guardar EEPROM)  g (estado)  h (ayuda)
 */

#include <Wire.h>
#include <EEPROM.h>
#include <ESP8266WiFi.h>
#include <ESP8266WebServer.h>

// ---------- Pines (Wemos D1 mini) -- identico a Test 01 ----------
#define MPU_ADDR      0x68
#define SDA_PIN       D2   // GPIO4
#define SCL_PIN       D1   // GPIO5

#define ENA_PIN       D3   // GPIO0  -- PWM canal A (rueda izquierda)
#define IN1_PIN       D0   // GPIO16 -- direccion canal A
#define IN2_PIN       D5   // GPIO14 -- direccion canal A
#define ENB_PIN       D4   // GPIO2  -- PWM canal B (rueda derecha)
#define IN3_PIN       D6   // GPIO12 -- direccion canal B
#define IN4_PIN       D7   // GPIO13 -- direccion canal B

// ---------- WiFi (AP propio -- no depende de router de casa) ----------
const char* WIFI_SSID     = "BalanceBot";
const char* WIFI_PASSWORD = "equilibrio"; // minimo 8 caracteres

ESP8266WebServer server(80);
String serialLineBuffer = "";

// ---------- Filtro complementario ----------
#define ALPHA         0.98f
#define LOOP_DT_MS    5

// ---------- EEPROM ----------
// Direcciones: 0=KP, 4=KI, 8=KD, 12=SETPOINT_ANGLE, 20=MOTOR_DEADZONE (floats, 4 bytes c/u), 16=magic byte
#define EEPROM_SIZE   32
#define EEPROM_MAGIC  0xA5

// ---------- PID (defaults del codigo -- se pisan si hay valores guardados en EEPROM) ----------
float KP = 0.0f;
float KI = 0.0f;
float KD = 1.0f;
float SETPOINT_ANGLE = 2.75f;

#define FALL_THRESHOLD_DEG 35.0f

// ---------- Estado global ----------
float pitch = 0.0f;
float lastOutput = 0.0f;
float gyroOffsetY = 0.0f;
float integral = 0.0f;
float lastError = 0.0f;
float filteredDerivative = 0.0f;
float DERIV_FILTER = 0.7f; // 0-1: mas alto = mas suave/lento, menos ruido pero mas retraso
unsigned long lastLoopMs = 0;
bool motorsEnabled = false; // arranca DESARMADO por seguridad

// ---------- MPU6050: acceso por registro crudo ----------
void mpuWrite(uint8_t reg, uint8_t val) {
  Wire.beginTransmission(MPU_ADDR);
  Wire.write(reg);
  Wire.write(val);
  Wire.endTransmission();
}

void mpuInit() {
  mpuWrite(0x6B, 0x00);
}

void mpuReadRaw(int16_t &ax, int16_t &ay, int16_t &az, int16_t &gx, int16_t &gy, int16_t &gz) {
  Wire.beginTransmission(MPU_ADDR);
  Wire.write(0x3B);
  Wire.endTransmission(false);
  Wire.requestFrom(MPU_ADDR, 14, true);

  ax = (Wire.read() << 8) | Wire.read();
  ay = (Wire.read() << 8) | Wire.read();
  az = (Wire.read() << 8) | Wire.read();
  Wire.read(); Wire.read();
  gx = (Wire.read() << 8) | Wire.read();
  gy = (Wire.read() << 8) | Wire.read();
  gz = (Wire.read() << 8) | Wire.read();
}

void calibrateGyro() {
  const int N = 500;
  long sum = 0;
  int16_t ax, ay, az, gx, gy, gz;
  for (int i = 0; i < N; i++) {
    mpuReadRaw(ax, ay, az, gx, gy, gz);
    sum += gy;
    delay(2);
  }
  gyroOffsetY = (sum / (float)N) / 131.0f;
}

// ---------- Motores ----------
void setupMotors() {
  pinMode(IN1_PIN, OUTPUT);
  pinMode(IN2_PIN, OUTPUT);
  pinMode(IN3_PIN, OUTPUT);
  pinMode(IN4_PIN, OUTPUT);
  analogWriteRange(255);
}

// Por debajo de MOTOR_DEADZONE el TT motor no vence su friccion estatica y
// no gira nada -- un error chico produce un PWM chico que se pierde sin
// mover la rueda, dejando el robot caer libre hasta que el error crece
// demasiado. Compensamos: cualquier salida distinta de cero se "levanta"
// al minimo necesario para que la rueda efectivamente gire.
float MOTOR_DEADZONE = 60.0f;

void setMotorChannel(int enaPin, int in1Pin, int in2Pin, float speed) {
  bool forward = speed >= 0;
  digitalWrite(in1Pin, forward ? HIGH : LOW);
  digitalWrite(in2Pin, forward ? LOW : HIGH);

  int duty = (int)fabs(speed);
  if (duty > 0 && duty < MOTOR_DEADZONE) duty = (int)MOTOR_DEADZONE;
  analogWrite(enaPin, duty);
}

void setMotors(float speed) {
  speed = constrain(speed, -255.0f, 255.0f);
  setMotorChannel(ENA_PIN, IN1_PIN, IN2_PIN, speed);
  setMotorChannel(ENB_PIN, IN3_PIN, IN4_PIN, speed);
}

void stopMotors() {
  analogWrite(ENA_PIN, 0);
  analogWrite(ENB_PIN, 0);
  digitalWrite(IN1_PIN, LOW);
  digitalWrite(IN2_PIN, LOW);
  digitalWrite(IN3_PIN, LOW);
  digitalWrite(IN4_PIN, LOW);
}

// ---------- EEPROM ----------
void saveToEEPROM() {
  EEPROM.put(0, KP);
  EEPROM.put(4, KI);
  EEPROM.put(8, KD);
  EEPROM.put(12, SETPOINT_ANGLE);
  EEPROM.put(20, MOTOR_DEADZONE);
  EEPROM.write(16, EEPROM_MAGIC);
  EEPROM.commit();
}

void loadFromEEPROMIfPresent() {
  if (EEPROM.read(16) != EEPROM_MAGIC) {
    Serial.println(F("EEPROM vacia -- usando valores default del codigo."));
    return;
  }
  EEPROM.get(0, KP);
  EEPROM.get(4, KI);
  EEPROM.get(8, KD);
  EEPROM.get(12, SETPOINT_ANGLE);
  EEPROM.get(20, MOTOR_DEADZONE);
  Serial.println(F("Valores cargados desde EEPROM."));
}

// ---------- Comandos por Serial (texto, igual que antes -- util con cable) ----------
void printHelp(Print &out) {
  out.println(F("--- Comandos ---"));
  out.println(F("p<val>  setear KP     (ej. p6.5)"));
  out.println(F("i<val>  setear KI     (ej. i0.1)"));
  out.println(F("d<val>  setear KD     (ej. d0.3)"));
  out.println(F("s<val>  setear SETPOINT_ANGLE (ej. s-1.2)"));
  out.println(F("e       armar motores"));
  out.println(F("x       desarmar motores (parada de emergencia)"));
  out.println(F("c       recalibrar giroscopo (robot quieto y plano)"));
  out.println(F("w       guardar gains actuales en EEPROM"));
  out.println(F("z<val>  setear zona muerta del motor (ej. z60)"));
  out.println(F("f<val>  setear suavizado de la derivada, 0-0.99 (ej. f0.7)"));
  out.println(F("g       imprimir estado actual"));
  out.println(F("h / ?   esta ayuda"));
}

void printStatus(Print &out) {
  out.print(F("KP=")); out.print(KP);
  out.print(F(" KI=")); out.print(KI);
  out.print(F(" KD=")); out.print(KD);
  out.print(F(" SETPOINT=")); out.print(SETPOINT_ANGLE);
  out.print(F(" DEADZONE=")); out.print(MOTOR_DEADZONE);
  out.print(F(" DERIV_FILTER=")); out.print(DERIV_FILTER);
  out.print(F(" pitch=")); out.print(pitch);
  out.print(F(" motores=")); out.println(motorsEnabled ? "ARMADOS" : "desarmados");
}

void armMotors() {
  motorsEnabled = true;
  integral = 0; lastError = 0; // arranca limpio, sin arrastrar error de cuando estaba desarmado
}

void processLine(const String &line, Print &out) {
  if (line.length() == 0) return;

  char cmd = line.charAt(0);
  float val = line.substring(1).toFloat();

  switch (cmd) {
    case 'p': KP = val; out.print(F("KP=")); out.println(KP); break;
    case 'i': KI = val; out.print(F("KI=")); out.println(KI); break;
    case 'd': KD = val; out.print(F("KD=")); out.println(KD); break;
    case 's': SETPOINT_ANGLE = val; out.print(F("SETPOINT_ANGLE=")); out.println(SETPOINT_ANGLE); break;
    case 'z': MOTOR_DEADZONE = val; out.print(F("MOTOR_DEADZONE=")); out.println(MOTOR_DEADZONE); break;
    case 'f': DERIV_FILTER = constrain(val, 0.0f, 0.99f); out.print(F("DERIV_FILTER=")); out.println(DERIV_FILTER); break;
    case 'e': armMotors(); out.println(F("Motores ARMADOS")); break;
    case 'x': motorsEnabled = false; stopMotors(); out.println(F("Motores DETENIDOS")); break;
    case 'c':
      out.println(F("Recalibrando giroscopo -- mantener quieto y plano..."));
      calibrateGyro();
      out.println(F("Listo."));
      break;
    case 'w': saveToEEPROM(); out.println(F("Guardado en EEPROM.")); break;
    case 'g': printStatus(out); break;
    case 'h':
    case '?': printHelp(out); break;
    default: out.println(F("Comando desconocido. Mandar 'h' para ayuda.")); break;
  }
}

// Lectura no bloqueante byte a byte: una lectura bloqueante (readStringUntil)
// congelaria el loop de balance de 200Hz mientras espera el resto de la linea.
void pollSerial() {
  while (Serial.available()) {
    char c = Serial.read();
    if (c == '\n') {
      serialLineBuffer.trim();
      processLine(serialLineBuffer, Serial);
      serialLineBuffer = "";
    } else if (c != '\r') {
      serialLineBuffer += c;
    }
  }
}

// ---------- Pagina web ----------
const char PAGINA[] PROGMEM = R"rawliteral(
<!DOCTYPE html>
<html>
<head>
<meta name="viewport" content="width=device-width, initial-scale=1">
<title>Balance PID Tuner</title>
<style>
  * { box-sizing: border-box; -webkit-tap-highlight-color: transparent; }
  body {
    margin: 0; padding: 16px;
    font-family: 'Segoe UI', Arial, sans-serif;
    background: radial-gradient(circle at top, #1e2530, #0d1117);
    color: #fff;
    display: flex; flex-direction: column; align-items: center;
  }
  h1 { font-size: 20px; letter-spacing: 1px; margin: 4px 0 16px;
       background: linear-gradient(90deg, #4CAF50, #2196F3);
       -webkit-background-clip: text; -webkit-text-fill-color: transparent; }
  .panel { background: #161b22; border-radius: 16px; padding: 18px;
           box-shadow: 0 8px 24px rgba(0,0,0,0.5); width: 100%; max-width: 380px; margin-bottom: 14px; }
  .status-row { display: flex; justify-content: space-between; font-size: 14px; color: #ccc; padding: 4px 0; }
  .status-row span.val { color: #fff; font-weight: 600; }
  #estadoTxt.armado { color: #4CAF50; }
  #estadoTxt.desarmado { color: #ffa726; }
  #estadoTxt.caido { color: #e53935; }
  .campo { display: flex; justify-content: space-between; align-items: center; margin-bottom: 10px; }
  .campo label { font-size: 13px; color: #ccc; }
  .campo input { width: 100px; padding: 6px; border-radius: 8px; border: 1px solid #333;
                 background: #0d1117; color: #fff; font-size: 14px; text-align: right; }
  button { border: none; border-radius: 12px; padding: 12px; font-size: 14px; font-weight: 600;
           color: #fff; width: 100%; margin-bottom: 8px; cursor: pointer;
           background: linear-gradient(145deg, #2b3542, #1c232c);
           box-shadow: 0 4px 10px rgba(0,0,0,0.4); }
  button:active { transform: scale(0.97); }
  #btnAplicar { background: linear-gradient(145deg, #2196F3, #1565C0); }
  #btnArmar { background: linear-gradient(145deg, #4CAF50, #2e7d32); }
  #btnParar { background: linear-gradient(145deg, #e53935, #b71c1c); font-size: 16px; }
  .fila2 { display: flex; gap: 8px; }
  .fila2 button { flex: 1; }
</style>
</head>
<body>

<h1>BALANCE PID TUNER</h1>

<div class="panel">
  <div class="status-row"><span>Angulo</span><span class="val" id="pitchTxt">--</span></div>
  <div class="status-row"><span>Output motor</span><span class="val" id="outputTxt">--</span></div>
  <div class="status-row"><span>Estado</span><span class="val" id="estadoTxt">--</span></div>
</div>

<div class="panel">
  <div class="campo"><label>KP</label><input id="p" type="number" step="0.1"></div>
  <div class="campo"><label>KI</label><input id="i" type="number" step="0.01"></div>
  <div class="campo"><label>KD</label><input id="d" type="number" step="0.1"></div>
  <div class="campo"><label>Setpoint (grados)</label><input id="s" type="number" step="0.1"></div>
  <div class="campo"><label>Zona muerta motor</label><input id="z" type="number" step="1"></div>
  <div class="campo"><label>Filtro derivada</label><input id="f" type="number" step="0.05" min="0" max="0.99"></div>
  <button id="btnAplicar" onclick="aplicar()">APLICAR</button>
</div>

<div class="panel">
  <button id="btnParar" onclick="accion('/stop')">PARAR (emergencia)</button>
  <div class="fila2">
    <button id="btnArmar" onclick="accion('/arm')">ARMAR</button>
    <button onclick="accion('/calibrate')">Recalibrar</button>
  </div>
  <button onclick="accion('/save')">Guardar en EEPROM</button>
</div>

<script>
function aplicar() {
  var ids = ['p','i','d','s','z','f'];
  var qs = ids.map(function(k){ return k + '=' + document.getElementById(k).value; }).join('&');
  fetch('/set?' + qs).catch(function(){});
}
function accion(path) {
  fetch(path).catch(function(){});
}

var camposCargados = false;

function actualizar() {
  fetch('/status').then(function(r){ return r.json(); }).then(function(j){
    document.getElementById('pitchTxt').textContent = j.pitch.toFixed(2) + '°';
    document.getElementById('outputTxt').textContent = j.output.toFixed(0);
    var estado = document.getElementById('estadoTxt');
    if (j.fallen) { estado.textContent = 'CAIDO'; estado.className = 'caido'; }
    else if (j.armed) { estado.textContent = 'ARMADO'; estado.className = 'armado'; }
    else { estado.textContent = 'desarmado'; estado.className = 'desarmado'; }

    // Los inputs solo se sincronizan una vez al cargar, para no pisar
    // mientras el usuario esta escribiendo un valor nuevo.
    if (!camposCargados) {
      document.getElementById('p').value = j.kp;
      document.getElementById('i').value = j.ki;
      document.getElementById('d').value = j.kd;
      document.getElementById('s').value = j.setpoint;
      document.getElementById('z').value = j.deadzone;
      document.getElementById('f').value = j.derivFilter;
      camposCargados = true;
    }
  }).catch(function(){});
}
actualizar();
setInterval(actualizar, 250);
</script>
</body>
</html>
)rawliteral";

// ---------- Handlers web ----------
void handleRoot() {
  server.send(200, "text/html", PAGINA);
}

void handleSet() {
  if (server.hasArg("p")) KP = server.arg("p").toFloat();
  if (server.hasArg("i")) KI = server.arg("i").toFloat();
  if (server.hasArg("d")) KD = server.arg("d").toFloat();
  if (server.hasArg("s")) SETPOINT_ANGLE = server.arg("s").toFloat();
  if (server.hasArg("z")) MOTOR_DEADZONE = server.arg("z").toFloat();
  if (server.hasArg("f")) DERIV_FILTER = constrain(server.arg("f").toFloat(), 0.0f, 0.99f);
  server.send(200, "text/plain", "OK");
}

void handleArm() {
  armMotors();
  server.send(200, "text/plain", "OK");
}

void handleStop() {
  motorsEnabled = false;
  stopMotors();
  server.send(200, "text/plain", "OK");
}

void handleCalibrate() {
  calibrateGyro();
  server.send(200, "text/plain", "OK");
}

void handleSave() {
  saveToEEPROM();
  server.send(200, "text/plain", "OK");
}

void handleStatus() {
  bool fallen = fabs(pitch - SETPOINT_ANGLE) > FALL_THRESHOLD_DEG;
  String json = "{";
  json += "\"pitch\":" + String(pitch, 2) + ",";
  json += "\"output\":" + String(lastOutput, 1) + ",";
  json += "\"armed\":" + String(motorsEnabled ? "true" : "false") + ",";
  json += "\"fallen\":" + String(fallen ? "true" : "false") + ",";
  json += "\"kp\":" + String(KP, 3) + ",";
  json += "\"ki\":" + String(KI, 3) + ",";
  json += "\"kd\":" + String(KD, 3) + ",";
  json += "\"setpoint\":" + String(SETPOINT_ANGLE, 2) + ",";
  json += "\"deadzone\":" + String(MOTOR_DEADZONE, 0) + ",";
  json += "\"derivFilter\":" + String(DERIV_FILTER, 2);
  json += "}";
  server.send(200, "application/json", json);
}

// ---------- Setup ----------
void setup() {
  Serial.begin(115200);
  delay(200);
  EEPROM.begin(EEPROM_SIZE);

  Wire.begin(SDA_PIN, SCL_PIN);
  Wire.setClock(400000);

  mpuInit();
  setupMotors();
  stopMotors();

  loadFromEEPROMIfPresent();

  Serial.println(F("Calibrando giroscopo -- mantener el robot quieto y plano..."));
  calibrateGyro();
  Serial.println(F("Listo. Motores DESARMADOS."));
  printStatus(Serial);

  WiFi.mode(WIFI_AP);
  WiFi.softAP(WIFI_SSID, WIFI_PASSWORD);
  Serial.print(F("WiFi AP '")); Serial.print(WIFI_SSID); Serial.println(F("' activa."));
  Serial.print(F("Abrir en el navegador: http://")); Serial.println(WiFi.softAPIP());

  server.on("/", handleRoot);
  server.on("/status", handleStatus);
  server.on("/set", handleSet);
  server.on("/arm", handleArm);
  server.on("/stop", handleStop);
  server.on("/calibrate", handleCalibrate);
  server.on("/save", handleSave);
  server.begin();

  lastLoopMs = millis();
}

// ---------- Loop ----------
void loop() {
  pollSerial();
  server.handleClient();

  unsigned long now = millis();
  if (now - lastLoopMs < LOOP_DT_MS) return;
  float dt = (now - lastLoopMs) / 1000.0f;
  lastLoopMs = now;

  int16_t ax, ay, az, gx, gy, gz;
  mpuReadRaw(ax, ay, az, gx, gy, gz);

  float accelPitch = atan2((float)ax, sqrt((float)ay * ay + (float)az * az)) * 180.0f / PI;
  float gyroRateY = (gy / 131.0f) - gyroOffsetY;
  pitch = ALPHA * (pitch + gyroRateY * dt) + (1.0f - ALPHA) * accelPitch;

  bool fallen = fabs(pitch - SETPOINT_ANGLE) > FALL_THRESHOLD_DEG;
  float output = 0.0f;

  if (fallen) {
    stopMotors();
    integral = 0;
    lastError = 0;
  } else if (motorsEnabled) {
    float error = pitch - SETPOINT_ANGLE;
    integral += error * dt;
    integral = constrain(integral, -255.0f, 255.0f);
    float rawDerivative = (error - lastError) / dt;
    lastError = error;
    // Derivada cruda amplifica ruido del sensor -- eso hace que KD reaccione
    // de forma erratica y empeora el rebote en vez de amortiguarlo. Se suaviza
    // con un filtro exponencial simple antes de usarla.
    filteredDerivative = DERIV_FILTER * filteredDerivative + (1.0f - DERIV_FILTER) * rawDerivative;

    output = constrain(KP * error + KI * integral + KD * filteredDerivative, -255.0f, 255.0f);
    setMotors(output);
  } else {
    stopMotors();
  }

  lastOutput = output;
}

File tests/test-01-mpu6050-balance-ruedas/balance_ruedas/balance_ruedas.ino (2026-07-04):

/*
 * Test 01 - MPU-6050 + balance sobre ruedas (TT motors via L298N)
 *
 * Ver README.md de esta carpeta: wiring completo, calibracion, tuning de PID,
 * criterio de exito y troubleshooting.
 *
 * Board: Wemos D1 mini (ESP8266), Arduino core. Solo depende de Wire.h -- el
 * MPU6050 se lee por registro crudo (sin libreria externa) para mantener el
 * test autocontenido.
 *
 * IMPORTANTE: este .ino es un flash TEMPORAL para el test. Si esta misma placa
 * normalmente corre el firmware de Head Node (OLED/mic/servos pan-tilt), hay
 * que reflashear ese firmware original al terminar -- los pines de este test
 * no son compatibles con esa asignacion (ver electronica/conexionado.md).
 */

#include <Wire.h>

// ---------- Pines (Wemos D1 mini) ----------
// Los 2 canales del L298N van cableados independientes (no atados entre si):
// se probo en esta placa que D0/D3/D4 (strapping pins en teoria sensibles al
// boot) funcionan sin problema como salidas digitales una vez arrancado el
// D1 mini. Dejar esto asi habilita un test futuro de giro/direccion sin
// recablear nada.
#define MPU_ADDR      0x68
#define SDA_PIN       D2   // GPIO4
#define SCL_PIN       D1   // GPIO5

#define ENA_PIN       D3   // GPIO0  -- PWM canal A (rueda izquierda)
#define IN1_PIN       D0   // GPIO16 -- direccion canal A (solo digitalWrite, GPIO16 no soporta PWM)
#define IN2_PIN       D5   // GPIO14 -- direccion canal A
#define ENB_PIN       D4   // GPIO2  -- PWM canal B (rueda derecha)
#define IN3_PIN       D6   // GPIO12 -- direccion canal B
#define IN4_PIN       D7   // GPIO13 -- direccion canal B

// ---------- Filtro complementario ----------
#define ALPHA         0.98f   // peso gyro vs accel; 0.98 es el valor tipico para MPU6050
#define LOOP_DT_MS    5       // 5ms -> ~200Hz, respuesta rapida necesaria para balance

// ---------- PID (arrancar todo en 0 y subir de a poco, ver README seccion "Tuning") ----------
float KP = 15.0f;
float KI = 0.0f;
float KD = 5.0f;

// Angulo real de equilibrio del robot. Depende de como quedo montado el MPU6050
// fisicamente -- rara vez es 0 exacto. Calibrar en campo (ver README "Calibracion").
float SETPOINT_ANGLE = 2.70f;

// Si se supera esta inclinacion respecto al setpoint, se asume caido: corta motores
// para no forzar los TT motors/engranajes contra el piso.
#define FALL_THRESHOLD_DEG 35.0f

// ---------- Estado global ----------
float pitch = 0.0f;
float gyroOffsetY = 0.0f;
float integral = 0.0f;
float lastError = 0.0f;
unsigned long lastLoopMs = 0;

// ---------- MPU6050: acceso por registro crudo ----------
void mpuWrite(uint8_t reg, uint8_t val) {
  Wire.beginTransmission(MPU_ADDR);
  Wire.write(reg);
  Wire.write(val);
  Wire.endTransmission();
}

void mpuInit() {
  mpuWrite(0x6B, 0x00); // PWR_MGMT_1: saca al MPU6050 de sleep mode (default al power-on)
}

// Lee accel(X,Y,Z) + gyro(X,Y,Z) crudos a partir de 0x3B (14 bytes, con temp en el medio)
void mpuReadRaw(int16_t &ax, int16_t &ay, int16_t &az, int16_t &gx, int16_t &gy, int16_t &gz) {
  Wire.beginTransmission(MPU_ADDR);
  Wire.write(0x3B);
  Wire.endTransmission(false);
  Wire.requestFrom(MPU_ADDR, 14, true);

  ax = (Wire.read() << 8) | Wire.read();
  ay = (Wire.read() << 8) | Wire.read();
  az = (Wire.read() << 8) | Wire.read();
  Wire.read(); Wire.read(); // temperatura, no se usa en este test
  gx = (Wire.read() << 8) | Wire.read();
  gy = (Wire.read() << 8) | Wire.read();
  gz = (Wire.read() << 8) | Wire.read();
}

// Promedia el giroscopo con el robot quieto y plano para restar su offset de reposo
// (todo MPU6050, sobre todo los clones baratos, tiene un offset de fabrica distinto de cero).
void calibrateGyro() {
  const int N = 500;
  long sum = 0;
  int16_t ax, ay, az, gx, gy, gz;
  for (int i = 0; i < N; i++) {
    mpuReadRaw(ax, ay, az, gx, gy, gz);
    sum += gy;
    delay(2);
  }
  gyroOffsetY = (sum / (float)N) / 131.0f; // 131 LSB/(deg/s), rango default +-250 deg/s
}

// ---------- Motores ----------
void setupMotors() {
  pinMode(IN1_PIN, OUTPUT);
  pinMode(IN2_PIN, OUTPUT);
  pinMode(IN3_PIN, OUTPUT);
  pinMode(IN4_PIN, OUTPUT);
  analogWriteRange(255); // ESP8266 usa 0-1023 por default; lo bajamos a 0-255
                         // para que coincida con las constantes del PID/anti-windup.
}

// Controla un canal del L298N (izquierda o derecha) de forma independiente.
void setMotorChannel(int enaPin, int in1Pin, int in2Pin, float speed) {
  bool forward = speed >= 0;
  digitalWrite(in1Pin, forward ? HIGH : LOW);
  digitalWrite(in2Pin, forward ? LOW : HIGH);
  analogWrite(enaPin, (int)fabs(speed));
}

// speed: -255..255. Signo = direccion, magnitud = PWM.
// Ambos canales reciben el mismo valor: este test es solo balance en el lugar.
// Como los canales estan cableados independientes, un test futuro de giro
// puede mandarles valores distintos sin tocar el hardware.
void setMotors(float speed) {
  speed = constrain(speed, -255.0f, 255.0f);
  setMotorChannel(ENA_PIN, IN1_PIN, IN2_PIN, speed); // izquierda
  setMotorChannel(ENB_PIN, IN3_PIN, IN4_PIN, speed); // derecha
}

void stopMotors() {
  analogWrite(ENA_PIN, 0);
  analogWrite(ENB_PIN, 0);
  digitalWrite(IN1_PIN, LOW);
  digitalWrite(IN2_PIN, LOW);
  digitalWrite(IN3_PIN, LOW);
  digitalWrite(IN4_PIN, LOW);
}

// ---------- Setup ----------
void setup() {
  Serial.begin(115200);
  Wire.begin(SDA_PIN, SCL_PIN);
  Wire.setClock(400000);

  mpuInit();
  setupMotors();
  stopMotors();

  Serial.println("Calibrando giroscopo -- mantener el robot quieto y plano...");
  calibrateGyro();
  Serial.println("Calibracion lista. Arrancando loop de balance.");

  lastLoopMs = millis();
}
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

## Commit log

2026-07-04 docs: scaffold bipedal robot project organization
    Set up vision/scope, system architecture, phased roadmap, risk log,
    electronics BOM/wiring/power budget, mechanical design notes, firmware
    architecture, gait control notes, and project management (backlog/milestones)
    for the bipedal robot, reusing the head subsystem (camera/voice/face) from
    the existing robotCreeper hardware.
2026-07-04 test: add wheel-balance sensor validation and live PID tuning tools
    - test-01: validates MPU-6050 + complementary filter + PID control loop
    on an ESP8266/Wemos D1 mini driving the L298N + TT motors as a
    temporary 2-wheel inverted-pendulum rig, ahead of committing to the
    leg mechanics.
    - test-02: live-tunable version (KP/KI/KD/setpoint/motor deadzone/
    derivative filter) via Serial commands and a WiFi web dashboard, with
    EEPROM persistence, so gains can be found without reflashing or being
    tethered by USB during balance tests.
    [autowifi.ino, balance_ruedas.ino, calibracion_pid.ino]
2026-07-05 docs: agrega plan de diseno 3D y referencias visuales
    Plan detallado para modelar el bipedo en CAD (esqueleto cinematico,
    inventario de componentes, flujo de modelado, checklists) antes de
    imprimir/fabricar piezas reales. Incluye analisis de las 3 imagenes
    de referencia en docs/3dImages, distinguiendo que tomar de cada una
    (proporciones reales vs inspiracion mecanica avanzada fuera de alcance
    vs estetica opcional).
2026-07-05 feat(cad): paso 1-2 diseno 3D — parametros y esqueleto en bloque
    Scripts FreeCAD reproducibles (via freecad-mcp execute_code):
    - paso01: spreadsheet ParametrosGenesis (altura objetivo, ROM, segmentos,
    MG996R) + celda derivada presupuesto_cabeza_placeholder (cabeza aun no
    existe, se disena en fase posterior) + stub de reserva de espacio.
    - paso02: esqueleto cinematico de una pierna con primitivas (cajas
    placeholder + cilindros marcadores de eje), todo parametrico por
    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
    [bipedalrobot_ensamble.FCStd]
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2026-07-05 feat(cad): paso 3 — pierna izquierda con detalle real
    Muslo/Pantorrilla/Pie reemplazan sus placeholders en el FCStd:
    - bolsillos pasantes para MG996R (datasheet + tolerancia provisional
    0.15mm), interfaces de horn, asiento de rodamiento en cadera,
    canales de cable senal/potencia, pie con doble apoyo talon+punta.
    - celdas provisionales nuevas en ParametrosGenesis (horn, rodamiento
    F688ZZ, offset de eje de servo) — pendientes de medir pieza fisica.
    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
    [bipedalrobot_ensamble.FCStd]
2026-07-06 feat(cad): paso 4 WIP — brackets de cadera roll+pitch (pierna izq)
    Dos piezas independientes que rotan entre si:
    - Bracket_Cadera_Roll_Izq: yugo con servo de roll (eje z=370) +
    rodamiento pasivo simetrico + flange de montaje al torso. Patron
    CADERA_TORSO_MOUNT_PATTERN fijado en ParametrosGenesis (4x M3 en
    +-31/+-14, plano z=355) — Paso 5 lo hereda sin redefinir.
    - Bracket_Cadera_Pitch_Izq: recibe roll por horn+perno M8, aloja el
    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
    [bipedalrobot_ensamble.FCStd]
2026-07-13 feat(sim): entorno PyBullet+RL (PPO) para marcha de cuadrupedo 12 DOF
    Experimento aislado en quadruped_rl_sim/, previo a portar el enfoque de
    RL con servos de posicion al robot bipedo real. Config parametrizable
    (config.py), generador de URDF (generate_urdf.py), entorno Gymnasium
    sobre PyBullet (quad_env.py), entrenamiento PPO vectorizado con
    stable-baselines3 (train.py) y visualizador GUI (enjoy.py).
    Validado de punta a punta: URDF carga sin error, reset/step con
    acciones aleatorias sin crashear, smoke test de train.py con
    DummyVecEnv y SubprocVecEnv (guard __main__ de Windows). pybullet no
    tiene wheel para Windows en PyPI, requiere VS Build Tools para
    compilar desde source (documentado en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
2026-07-13 feat(sim): agrega --resume a train.py para continuar entrenamientos cortados
    Ctrl+C, corte de luz, etc no deberian obligar a arrancar de cero. Carga el
    .zip de un checkpoint via PPO.load y sigue con reset_num_timesteps=False
    para que el contador de steps continue en vez de reiniciar. Probado contra
    un checkpoint real (400k steps) generado por el usuario.
    Claude-Session: https://claude.ai/code/session_01BFMJ5DhSEvjdG9Aq5yWnRe
2026-07-13 fix(sim): envuelve los envs con Monitor para que tensorboard loguee rollout/*
    Sin Monitor, SB3 no detecta el fin de episodio (no hay info["episode"]),
    asi que rollout/ep_rew_mean y rollout/ep_len_mean nunca aparecian en
    tensorboard -- solo se veian las secciones time/ y train/, justo las
    metricas menos utiles para saber si el entrenamiento progresa.
    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
2026-07-13 feat(sim): agrega marcador visual amarillo en el frente del torso
    Sin nada que distinga adelante/atras a simple vista en el GUI, era dificil
    confirmar la orientacion del robot solo mirando capturas. Caja chica
    amarilla fija en la cara +X del torso (la direccion que premia el reward
    de avance en quad_env.py). Solo visual/masa despreciable, no cambia la
    fisica ni el mapeo de joints (por nombre, no por indice) -- no requiere
    reentrenar modelos existentes.
    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
2026-07-13 feat(sim): actualiza config.py con medidas reales del chasis spider-open-v1
    Reemplaza los placeholders de dimensiones (torso, cadera, femur, tibia) por
    las medidas reales tomadas del CAD SketchUp del robot que se va a usar para
    la implementacion fisica (confirmado 12 DOF, 3 servos independientes por
    pata, misma arquitectura ya construida). Torso paso de 30cm a 14.6cm,
    alcance de pata de 24cm a ~13cm -- se recalculo TARGET_STANDING_HEIGHT y
    MIN_TORSO_HEIGHT en proporcion.
    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
2026-07-13 feat(sim): estima masas del chasis spider-open-v1 (12x MG90S, PLA, demo)
    Reemplaza los placeholders de masa por una estimacion con supuestos
    explicitos en los comentarios: PLA con densidad efectiva ~620 kg/m3 en
    brackets chicos (infill tipico), plancha del torso casi solida (~4mm),
    12x servo MG90S (13.4g c/u, 2 en la cadera + 1 en el femur por pata),
    ESP32+PCA9685+cableado (~35g), bateria generica chica (~60g, sin definir
    todavia). Masa total resultante: ~687g, verificada sumando todos los
    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
2026-07-13 feat(sim): agrega notebook de Colab para entrenar en la nube
    Permite entrenar sin depender de la laptop prendida: monta Google Drive,
    clona/actualiza el repo ahi (persistencia entre sesiones de Colab, que
    desconecta solo cada rato), instala requirements.txt (pybullet si tiene
    wheel en Linux, a diferencia de Windows), y entrena en tandas con
    auto-resume via el --resume que ya tiene train.py -- cada vez que se
    vuelve a correr la celda, siga desde el ultimo checkpoint en Drive.
    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
2026-07-14 fix(sim): postura real de arania (patas en diagonal, no tipo perro)
    El robot real (spider-open-v1) monta las 4 patas en diagonal hacia las
    esquinas del torso (silueta en X vista desde arriba), no perpendiculares
    al costado como un cuadrupedo mamifero. Cambios:
    - generate_urdf.py: nuevo SPIDER_SPLAY_DEG (yaw de montaje por pata hacia
    su esquina diagonal). Bug encontrado y corregido en el mismo cambio: el
    eje de abduccion estaba definido igual para las 4 patas, pero por el
    montaje diagonal (signo opuesto entre izq/der), un mismo angulo
    comandado producia movimiento correcto de un lado y deformado del otro
    -- se invierte el eje local segun el lado (sign_y), verificado
    numericamente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
2026-07-14 fix(sim): agrega fix de setuptools en colab_train.ipynb para tensorboard
    Bug reportado por el usuario corriendo el notebook: tensorboard en Colab
    (Python 3.12) revienta con "AttributeError: module 'pkgutil' has no
    attribute 'ImpImporter'" por una version vieja de setuptools -- bug
    conocido del combo Python 3.12 + setuptools viejo, no relacionado al
    proyecto. Se agrega "pip install -U setuptools" antes de instalar
    requirements.txt para evitarlo de raiz.
    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
